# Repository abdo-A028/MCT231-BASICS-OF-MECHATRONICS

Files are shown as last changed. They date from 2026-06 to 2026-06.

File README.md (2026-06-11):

# MCT231-BASICS-OF-MECHATRONICS
MCT231 Mechatronics Project: A fully integrated, standalone system featuring sorting, lifting, and closed-loop projectile mechanisms. Built with a custom PCB, strict cable management, and robust safety standards. It includes Bluetooth PC comms, an on-board LCD, and a visual Processing GUI. Repo contains all Code, CAD, and Docs.
# PlanetSort: OrbitQuest 🌌

An autonomous, space-themed interactive mechatronic system designed as an educational STEM toy. The project features automated color-based planet sorting, continuous vertical elevator lifting, and a calibrated dual-wheel friction projectile launcher. 

Developed as the Final Project for the **Basics of Mechatronics (MCT231)** course under the partnership of **Ain Shams University** and the **University of East London**.

---

## 👥 Mission Control Team (Team #16)
* **Ziad Atef M. Riad** - ID: 24P0103
* **Kamal Wahdan** - ID: 24P0222
* **Zeyad Amr Nazih** - ID: 24P0372
* **Yahya Ashraf** - ID: 24P0370
* **Abdoulrahman Adel** - ID: 24P0098

---

## 📸 Physical Prototype Showcase

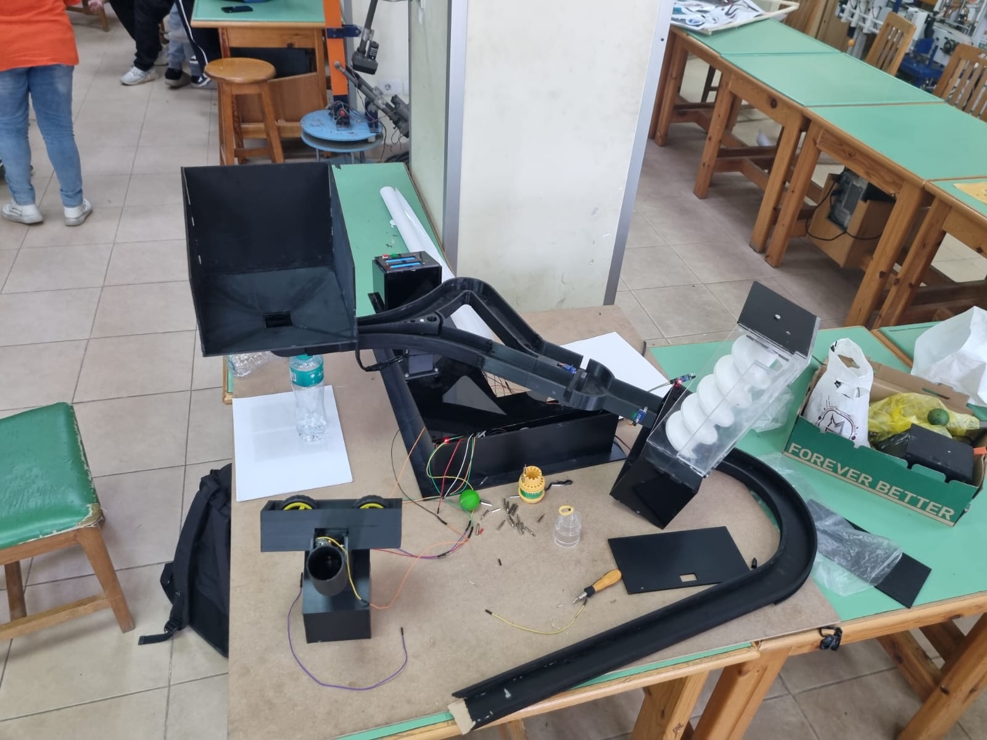
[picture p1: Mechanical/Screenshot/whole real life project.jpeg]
PlanetSort OrbitQuest System Setup


---

## 🚀 Project Architecture Overview
**PlanetSort: OrbitQuest** is engineered as a fully closed-loop, self-contained system running within a strict 100 cm x 100 cm x 100 cm volume. The product gamifies automation principles by treating different colored marbles as distinct planets navigating an interstellar transit grid. 

The system runs entirely off a single unified **12V DC power supply** and delegates tasks across a low-latency, wireless **Dual-ESP32 Master-Slave network** using the ESP-NOW protocol.

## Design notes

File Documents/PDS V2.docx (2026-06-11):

3. Product Design Specification (PDS)

The design and manufacturing boundaries of the PlanetSort: OrbitQuest mechatronic system are strictly governed by the following engineering criteria, established in accordance with course constraints and childhood safety standards:

Parameter ID | Category | Performance Requirement | Quantitative Target Metric | Priority (D/W) | Engineering Justification & Source
PDS-01 | Performance | Primary Functional Cycle | Complete autonomous color-based scanning, helical elevation, and parabolic projectile tracking. | D | Fulfills core mechatronic module requirements defined by the teaching committee.
PDS-02 | Performance | Closed-Loop Path Execution | 1 single ball loading point; 100 percent internal containment tracking throughout the complete operational loop. | D | Eradicates loose rolling pieces and ensures total containment of loose parts during the full loop.
PDS-03 | Mechanical | Ball Classification (Sorting) | Automated color identification via wavelength checks to separate balls into 2 divergent channels. | D | Driven by a TCS3200 sensor array acting on dual SG90 micro-servo flipper gates.
PDS-04 | Mechanical | Vertical Lifting Mechanism | Enclosed helical vertical transit lifting columns safely transporting marbles. | D | Employs an Archimedes spiral screw coupled to a NEMA 17 stepper motor running via an A4988 driver.
PDS-05 | Mechanical | Projectile Launch Subsystem | Friction-driven twin counter-rotating projection engine angled at a fixed incline. | D | Calibrated via PWM duty cycles to achieve an exit velocity of v0 = 4.15 m/s at a fixed 30-degree launch angle.
PDS-06 | Control | Embedded Processing Nodes | Dual-microcontroller processing grid mapping tasks across independent domains. | D | Deploys 2 x ESP32 DevKitC boards communicating wirelessly via low-latency peer-to-peer ESP-NOW protocol.
PDS-07 | Control | Local User Interface | Direct visual character menu terminal output (Seven-Segment configurations are strictly prohibited). | D | Employs 2 x onboard 16x4 character I2C LCD displays showing real-time subsystem state tracking.
PDS-08 | Control | Remote Monitoring Terminal | Wireless graphical monitoring software providing score and color parameter logging. | W | Achieved through a custom Processing.io application interacting via integrated Bluetooth Serial Port Profile.
PDS-09 | Electrical | Power Infrastructure | Single, unified power input terminal block layout supplying the entire backplane. | D | Eradicates independent secondary battery networks; safely driven by a single 12V, 5A DC adapter power source.
PDS-10 | Electrical | Onboard Voltage Regulation | Local voltage step-down buses to distribute isolated logic and actuator rails. | D | Integrates LM2596-based buck converter circuits on the custom PCB to step down 12V input to a stabilized 5V rail.
PDS-11 | Electrical | Custom Manufacturing | Clean signal routing and integration of system hardware components. | D | Mandates a minimum of 1 custom-manufactured PCB serving as the power distribution and circuit protection hub.
PDS-12 | Physical | Volumetric Footprint Bounds | Total external packaging bounds must remain within a compact structural envelope. | D | Maximum allowable boundaries of 100 cm x 100 cm x 100 cm; nominal layout optimized at 70 cm x 60 cm.
PDS-13 | Physical | Structural Composition | Non-toxic, rigid, drop-resistant material profiles with post-processed sanded facings. | D | Utilizes child-safe, deburred 3D-printed PLA mechanical paths mounted securely on a smooth 6 mm MDF baseboard.
PDS-14 | Physical | Structural Modularity | Subsystem mechanical arrays must cleanly decouple for maintenance. | D | Divided into 3 distinct modules (Sorting, Lifting, Shooting) using dedicated, polarized JST cable harnesses.
PDS-15 | Safety | Hazard & Shock Proofing | 100 percent concealment of electronic terminals and moving columns from user contact. | D | All electrical wiring is routed through integrated internal tracks; the helical lifter is encased inside clear acrylic.
PDS-16 | Safety | Ingestion Hazard Control | Planetary marble diameter sizing must remain strictly above choke testing cylinder limits. | D | Marble diameters are constrained between 35 mm and 40 mm to achieve compliance with global small parts toy safety criteria.
PDS-17 | Safety | Overcurrent Circuit Defense | Automatic hardware-level current trip points to protect logic lines if a mechanism stalls. | D | Features an inline, resettable polymeric 5A PTC fuse positioned immediately after the primary 12V DC power jack.
PDS-18 | Safety | Emergency System Shutdown | Instantaneous operational override path to halt all active actuators concurrently. | D | Physical, high-priority tactile push buttons configured to force immediate low-level hardware firmware interrupts.

The D/W Priority Filter: By explicitly labeling safety and course specifications as absolute a Demand (D) and a Wish (W), you show the panel that risk mitigation was treated as a primary engineering objective from day one.

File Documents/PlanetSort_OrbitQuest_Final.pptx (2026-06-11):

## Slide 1


PLANETSORT: ORBITQUEST

Advanced Interactive Mechatronic Product Design System

Ain Shams University · University of East London · Project Defense 2026

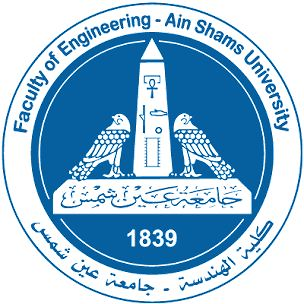
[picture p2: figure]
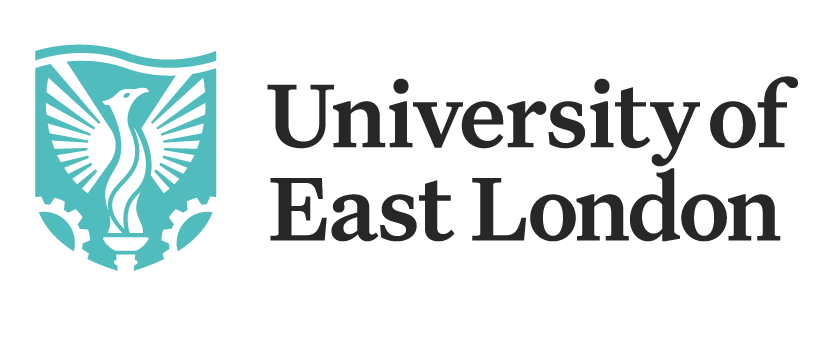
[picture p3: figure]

ARES SECTOR
RED ORBIT

GAEA SECTOR
GREEN ORBIT

Ziad Atef M. Riad
24P0103

Kamal Wahdan
24P0222

Zeyad Amr Nazih
24P0372

Yahya Ashraf
24P0370

Abdoulrahman Adel
24P0098

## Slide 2

PHASE I: VISION

Designing an autonomous, space-themed
planetary sorting and launching system

focused on cognitive development and STEM engagement.

Real project prototype — assembled for defense

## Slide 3

User Research & Target Persona

Primary Audience

Children aged 2–10 years. Focused research indicates high engagement for age 8 through visually stimulating mechanical feedback and goal-oriented tasks.

Core Needs

Visual stimulation (moving parts), color recognition, hand-eye coordination, and a safe, intuitive interface for 'closed-loop' play.

2–10

Target Age Range

3

Core Modules

100×100

cm Footprint

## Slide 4

The Design Challenge

Automated Sorting

Autonomous color detection and path routing using optical sensing logic.

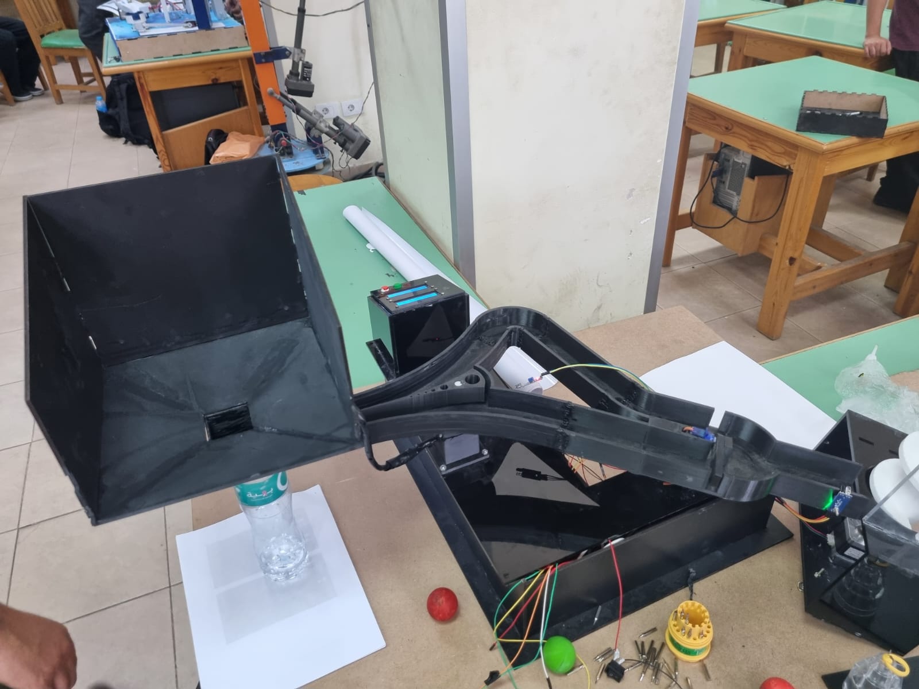
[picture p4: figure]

Vertical Lifting

Continuous vertical transit via an Archimedes spiral mechanism.

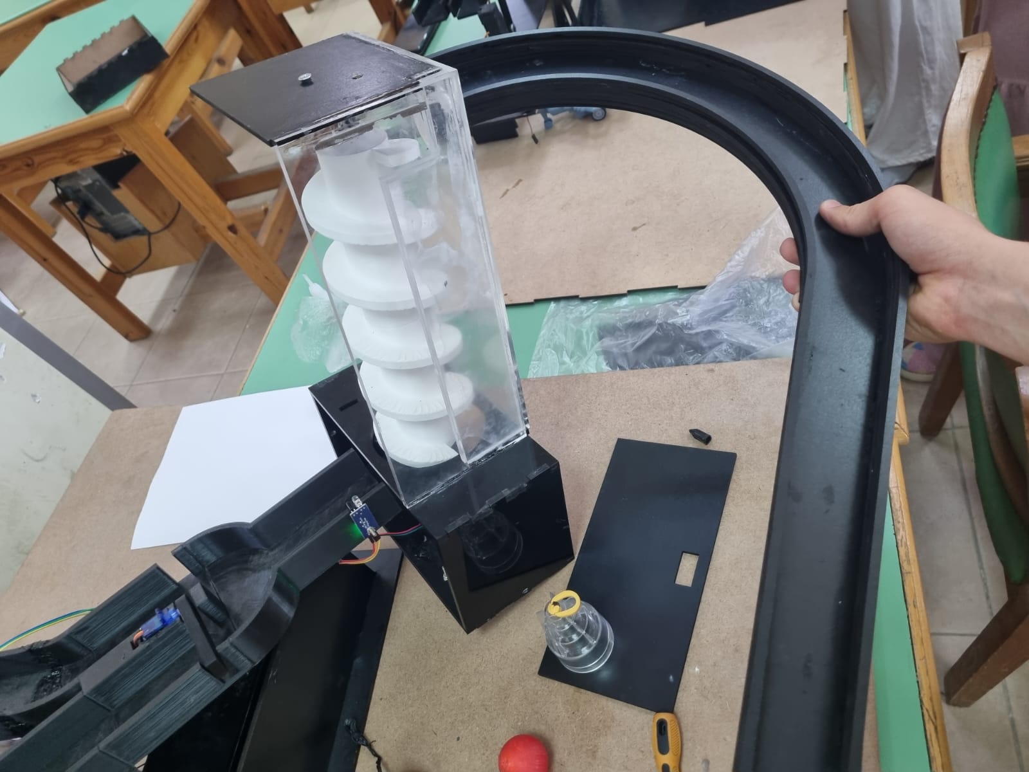
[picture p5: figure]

Orbital Launch

High-velocity calibrated projection into a target basketball hoop.

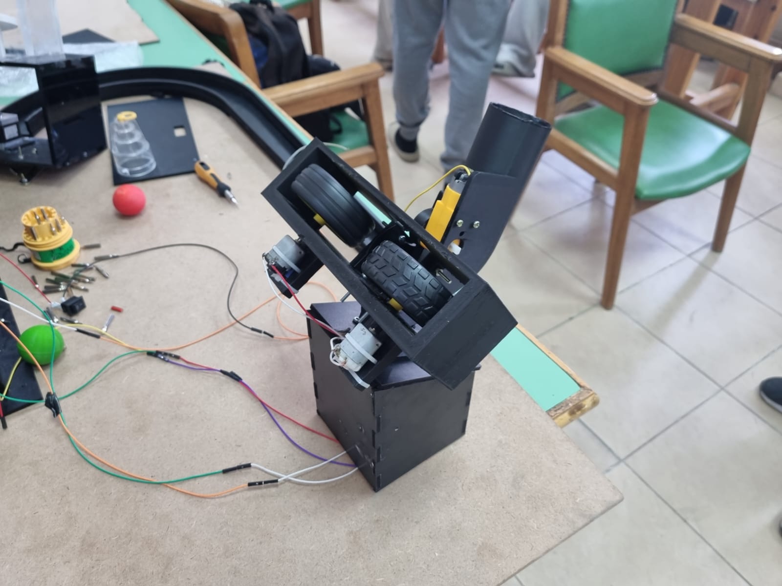
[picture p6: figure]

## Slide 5

Module I: PlanetScan Sorting

The sorting subsystem identifies planetary marbles by wavelength using the TCS3200 sensor array. Dual SG90 micro-servos actuate high-speed gates to route the spheres.

Real-time RGB frequency analysis

Non-contact optical gating

Dynamic error-correction routing

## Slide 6

Module II: Orbital Elevator

Our lifting mechanism utilizes a NEMA 17 stepper motor to drive a 3D-printed helical flight screw within a smooth-walled cylinder.

This module provides precise vertical positioning for the launch bay, ensuring the system is ready for the high-velocity shooting phase.

NEMA 17 Stepper

Motor:

Archimedes Spiral

Mechanism:

3D-Printed PLA

Material:

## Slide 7

Module III: Hyperspace Thruster

The shooting module utilizes twin counter-rotating friction wheels driven by high-RPM DC motors. Calibration ensures repeatable orbital injection.

By modulating the PWM duty cycle, we achieve the precise initial velocity required to overcome gravity and reach the target hoop.

4.15 m/s

Calibrated Launch Velocity · β = 30°

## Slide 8

Master-Slave Control Logic

ESP32 Master

Handles high-level tasks: Color sensing, TFT display, Bluetooth telemetry, and ESP-NOW communication with the slave controller.

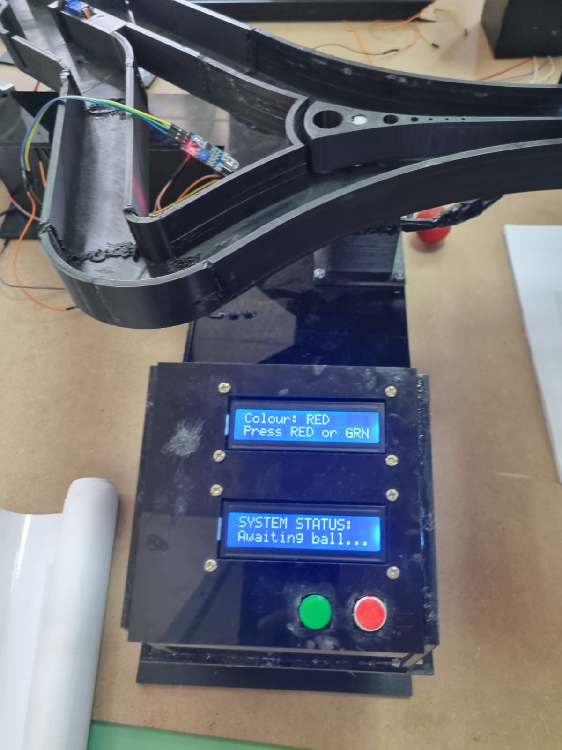
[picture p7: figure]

Arduino Uno Slave

Dedicated to low-level actuation: Precise stepper pulses, DC motor PWM curves, and servo timing isolation.

Communication via ESP-NOW wireless protocol · 2.4 GHz band

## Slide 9

Dual Interfaces: Mission Control

LCD Control Panel

Local onboard display · Colour detection readout
Green & Red button input

Ball Sorter App

Bluetooth remote control · Score tracking
Shoot speed slider · RGB sensor raw data

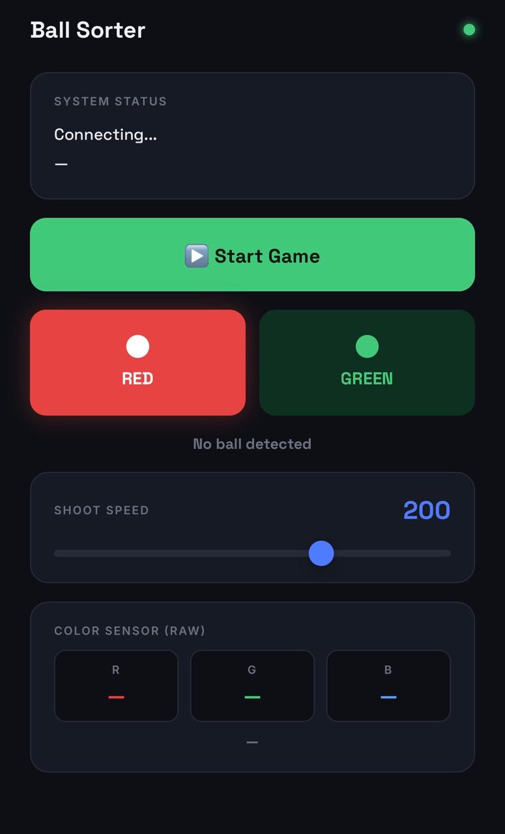
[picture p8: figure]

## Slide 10

Engineering Validation

v_o = d/(cos(β)) × √(g/(2(d·tan(β)− h)))≈ 4.15 m/s

Parameter | Value | Validation Status
Initial Velocity (v₀) | 4.15 m/s | Calculated & Tested
Launch Angle (β) | 30° | Fixed Mechanical Constraint
Current Draw (Max) | < 5.0 A | Fused Safety Limit
Motor Safety Factor | > 2.2 | Industry Standard Compliant

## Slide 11

Safety & Compliance Protocols

Concealed Architecture

All electrical wiring routed through internal structural channels to remain completely hidden and safe.

Thermal Safety

Onboard resettable 5A PTC fuse safeguards logic and motor rails against stall-current overloads and overheating.

Child-Safe Materials

Non-toxic PLA and smoothed MDF surfaces eliminate sharp edges and chemical exposure risks.

Hardware Interrupt

A physical master-stop button provides immediate electrical isolation of all high-power actuators.

OrbitQuest: Launching Curiosity into STEM · Ain Shams University & University of East London · Project Defense 2026

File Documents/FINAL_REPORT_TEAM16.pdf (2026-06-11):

## 16Table of Contents

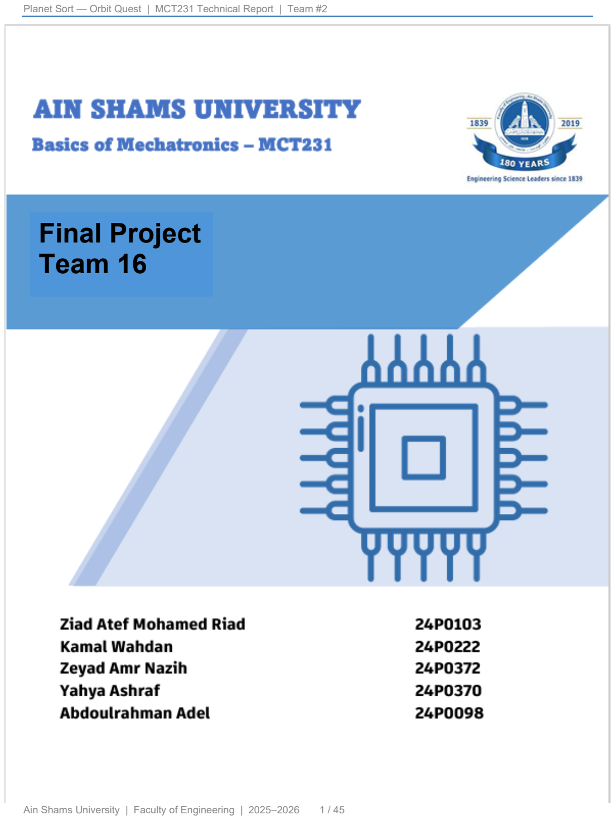
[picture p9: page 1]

Planet Sort — Orbit Quest | MCT231 Technical Report | Team #2
Ain Shams University | Faculty of Engineering | 2025–2026 1 / 45

# Final Project Team 16

Ain Shams University | Faculty of Engineering | 2025–2026 2 / 45

Ain Shams University | Faculty of Engineering | 2025–2026 3 / 45

Ain Shams University | Faculty of Engineering | 2025–2026 4 / 45

## 1. Introduction

Planet Sort (marketed to children as Orbit Quest) is an interactive, space-themed mechatronic toy designed for children aged 2–10. The toy presents a fully automated ball-sorting and launching system, where coloured planetary marbles are loaded, sorted by colour, lifted vertically via an Archimedes screw, and launched toward a target through a high-velocity shooting mechanism.
The project was developed as part of the MCT231 Basics of Mechatronics final project at Ain Shams University in collaboration with the University of East London. It integrates mechanical design, electronics, embedded firmware, and product design into a cohesive educational toy that fosters engagement, colour recognition, and curiosity in STEM topics.

### 1.1 Project Objectives

- Design and fabricate a fully functional electromechanical toy that integrates three distinct mechanisms: colour sorting, vertical lifting, and projectile shooting.
- Implement a dual-microcontroller architecture using two ESP32 boards communicating via the ESP-NOW wireless protocol.
- Provide two user interfaces: an onboard LCD display and a Bluetooth-connected Processing IO application.
- Ensure all mechanical, electrical, and firmware subsystems work as a closed-loop marble pathway.
- Document the complete design process from user research to final prototype.

Ain Shams University | Faculty of Engineering | 2025–2026 5 / 45

## 2. Design Thinking Process

### 2.1 User Research

The target audience was defined as children aged 2–10, with a primary engagement focus on children around 8 years old. User research revealed several key insights:
- Children in this age group are highly motivated by fast-moving, visually stimulating toys.
- Space and planetary themes score very high in engagement for both boys and girls.
- Simple, colour-based interactions are accessible even to younger children, while the automated mechanics provide complexity for older users.
- Safety is paramount: no sharp edges, no exposed wiring, and no small detachable parts that can be swallowed by younger children.

### 2.2 Design Challenge

The core design challenge was: How can we create a toy that is simultaneously engaging for a broad age range, educational in its interactions, safe by construction, and technically complex enough to demonstrate a complete mechatronic system?
The answer was to build a closed-loop automated machine themed around space and planet sorting, where the child's role is limited to choosing which colour marble to sort and watching the machine respond. This lowers the barrier of entry for younger children while still delighting older ones with the engineering of the system.

### 2.3 Ideation & Concept

Several concepts were explored via mind maps and mood boards before settling on the Planet Sort concept:
- Option A: Basketball-themed shooter with coloured balls. Relatable but not highly original.
- Option B: Recycling plant (similar to course example). Educational but less engaging visually.
- Option C: Planet Sort — space-themed sorting and launching of planetary marbles (Mars = red, Earth = green). Selected for its strong visual theme, broad age appeal, and alignment with all three required mechanisms.

### 2.4 Iterative Design

The design went through multiple iterations:
1. Initial sketches established the layout: screw lifter on the left, sorting gate in the middle channel, shooting mechanism at the top right.
2. CAD modelling in Autodesk Inventor refined dimensions and verified fit within the 100 cm × 100 cm constraint.
3. Wiring diagrams were drafted in Cirkit Designer, separating the three subsystems for modularity.
4. Physical prototyping with 3D-printed parts led to revisions in the screw pitch and the servo gate angle.

Ain Shams University | Faculty of Engineering | 2025–2026 6 / 45

## 3. Product Design Specification (PDS)

### 3.1 Performance & Functional Requirements

Requirement | Specification
Primary Function | Automated colour-based sorting, vertical lifting and projectile launching of planetary marbles.
Sorting Mechanism | TCS3200 colour sensor detects Red or Green marble. Two SG90 servo-driven gates direct the marble to the correct channel.
Lifting Mechanism | NEMA 17 stepper-driven Archimedes screw lifts marbles from the lower channel to the shooting platform.
Shooting Mechanism | Dual FA-130RA-18100 DC motors spinning rubber-rimmed wheels accelerate the marble to approx. 4.15 m/s at 30° launch angle over a 0.8 m range.
Closed-Loop Path | Single marble entry point; marbles remain within the internal track throughout operation.
User Interaction | Start/Stop button, Red/Green colour selection buttons, and onboard LCD display feedback.

### 3.2 Electronics & Control System

Parameter | Specification
Microcontrollers | 2× ESP32 (DevKitC). MCU1 handles sorting and lifting. MCU2 handles shooting and display.
Communication | ESP-NOW wireless peer-to-peer protocol (low-latency, no router required).
User Interface 1 | 2× 16×4 I2C LCD displays showing system state, selected colour, and mode (manual / Bluetooth).
User Interface 2 | Processing IO Bluetooth application on Android/PC — Start, Stop, colour selection.
Custom PCB | Power distribution board with 12 V input, PTC fuse, reverse-polarity diode, 12 V→5 V buck converter, and modular connectors for all subsystems.
Power Source | Single 12 V DC supply (adapter or 12 V LiPo battery). Four buck converters regulate to 5 V for logic and servos.

### 3.3 Physical & Material Specifications

Parameter | Specification
Dimensions | Maximum 100 cm × 100 cm footprint. Nominal design: ~70 cm × 60 cm.
Materials | PLA 3D-printed structural and mechanical parts. MDF base board. Smooth surfaces with no sharp edges.
Modularity | Three independent wiring modules (Sorting, Lifting, Shooting) with dedicated JST plug connectors to a central PCB.

Ain Shams University | Faculty of Engineering | 2025–2026 | 7 / 45
Safety | All wiring concealed inside channels. No exposed moving pinch points. Marble diameter >35 mm (not a choking hazard for ages 2+).

### 3.4 Target Audience

- Primary: Children aged 6–10 years — full autonomous use.
- Secondary: Children aged 2–5 years — supervised play; adult loads marbles and selects colour.
- Tertiary: Parents/educators — observe educational value in STEM, colour recognition, and cause-and-effect reasoning.

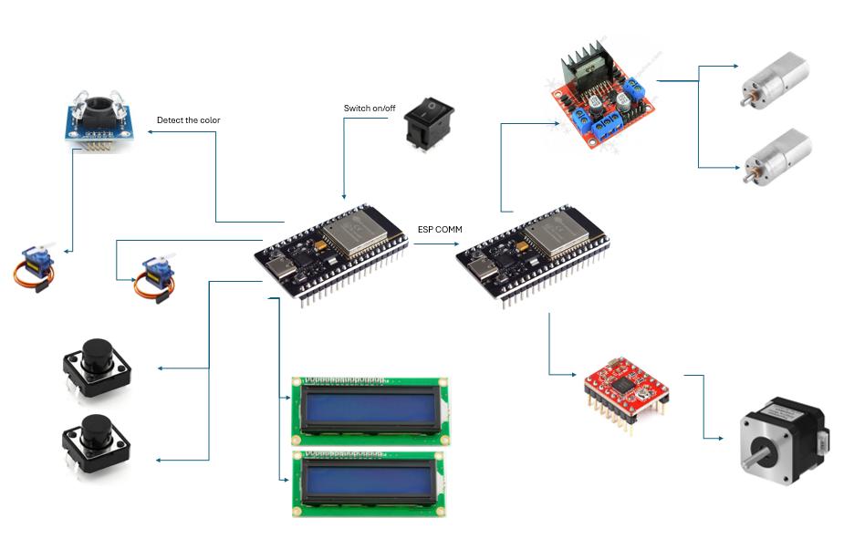
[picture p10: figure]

Ain Shams University | Faculty of Engineering | 2025–2026 8 / 45

## 4. System Architecture

### 4.1 Block Diagram Overview

The system is divided into two microcontroller domains connected by ESP-NOW wireless communication:

MCU 1 — Sorting & User Input (ESP32 #1)
- Inputs: TCS3200 colour sensor, Colour 1 button, Colour 2 button, On/Off switch.
- Outputs: Selecting servo (path gate), Sorting servo (end gate), 16×4 I2C LCD display #1.
- Transmits: Colour decision and start/stop command to MCU2 via ESP-NOW.

MCU 2 — Lifting, Shooting & Feedback (ESP32 #2)
- Inputs: ESP-NOW message from MCU1.
- Outputs: A4988 stepper driver → NEMA 17 (Archimedes screw), L298N H-bridge → 2× DC motors (shooting wheels), 16×4 I2C LCD display #2.

### 4.2 System Flowchart

The following describes the operational logic of the complete system:
5. Balls are placed into the selection mechanism (entry point). System starts on button press.
6. Default colour is set to Colour 1 (Green). LCD outputs 'Select Color'.
7. User presses Green or Red button (or selects via Bluetooth app).
8. Is Color 1 (Green) selected? If YES: Path 1 stays open. If NO: Path 1 closes, Path 2 opens.
9. Ball moves through the selected path to the sorting mechanism.

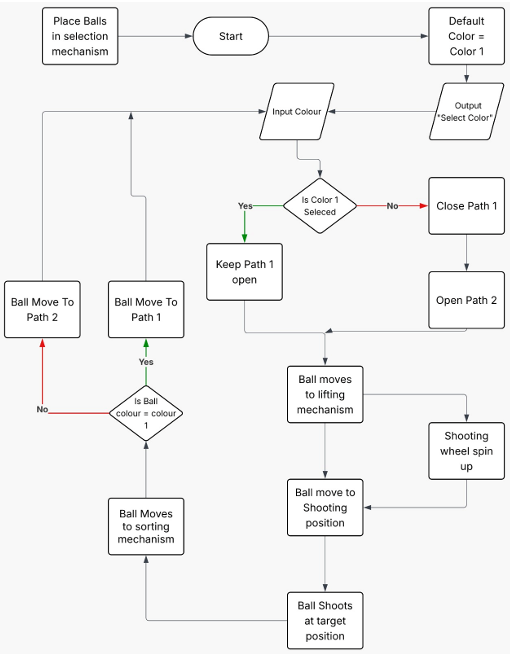
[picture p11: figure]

Ain Shams University | Faculty of Engineering | 2025–2026 9 / 45
10. Colour sensor reads the ball. Is ball colour = selected colour? If YES: Ball moves to lifting mechanism. If NO: Ball returns to sorting mechanism.
11. Ball is lifted by Archimedes screw to shooting platform.
12. Shooting wheels spin up to operating speed (~1,743 rpm).
13. Ball moves to shooting position and is launched toward target.
14. Cycle completes; system awaits next ball or Stop command.

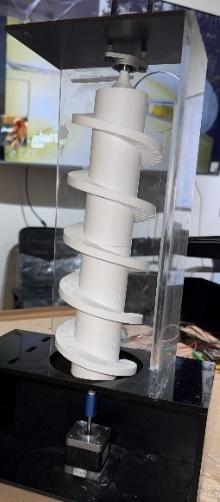
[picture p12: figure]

Ain Shams University | Faculty of Engineering | 2025–2026 10 / 45

## 5. Mechanical Design

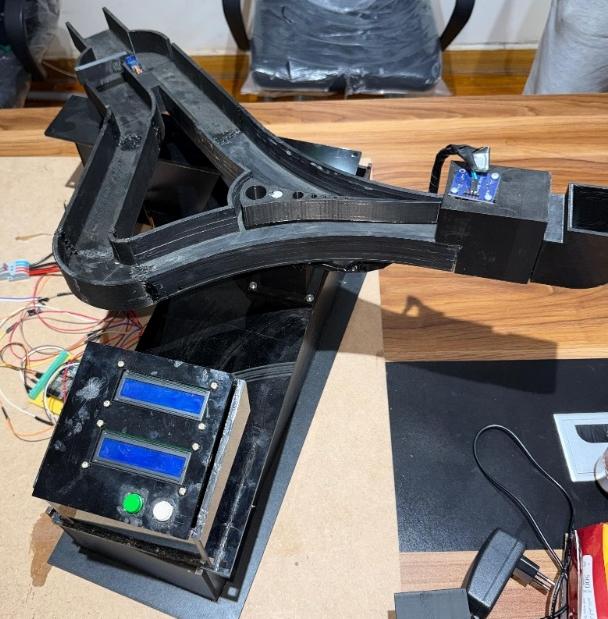
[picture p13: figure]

### 5.1 Sorting Mechanism

The sorting mechanism uses two SG90 micro servo motors to actuate gate flaps within the marble channel:
- Selecting Servo: Acts as the initial path router. When Color 1 is selected, the flap remains in position to keep Path 1 open. When Color 2 is selected, the flap rotates to close Path 1 and open Path 2.
- Sorting Servo (End Gate): Positioned at the output of the colour-sensing zone. After the TCS3200 confirms the correct colour, this servo opens to release the marble to the lifting mechanism. If the colour does not match, it redirects the marble back.
- CAD: Both gate mechanisms are 3D-printed in PLA. Servo horn connectors are press-fit with M2 screws for easy replacement.

### 5.2 Lifting Mechanism — Archimedes Screw

The vertical lifting mechanism is based on an Archimedes screw — a helical blade wound around a central shaft enclosed in a smooth cylindrical tube:
- Motor: NEMA 17 stepper motor (operating at ~500 rpm) drives the screw shaft via a direct-drive coupler.
- Screw dimensions: Pitch and diameter sized to accept marbles of 35–40 mm diameter and transport one marble per revolution reliably.
- The enclosed tube prevents marbles from falling sideways and contributes to the closed-loop pathway requirement.
- All parts 3D-printed in PLA. The screw was printed in sections and assembled on the shaft.

### 5.3 Shooting Mechanism

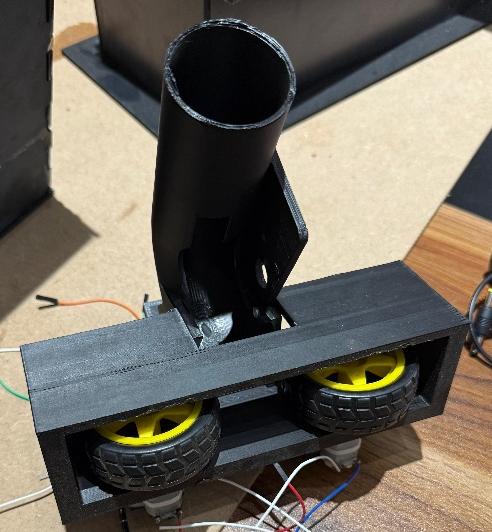
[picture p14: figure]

The shooting mechanism uses a dual-wheel friction launcher, widely used in table tennis ball machines and youth sports equipment:
- Two FA-130RA-18100 DC motors each drive a rubber-rimmed PLA wheel (~65 mm diameter, 35 g).
- The wheels are arranged facing each other with a gap slightly smaller than the marble diameter, creating a compression grip.
- When the marble is fed between the spinning wheels, friction accelerates it to the calculated exit velocity (~4.15 m/s).
- Motor driver: L298N H-bridge controlled via PWM from MCU2, allowing speed adjustment.
- Launch angle: 30° above horizontal, achieving a 0.8 m horizontal range at a 0.2 m height difference to the target hoop.

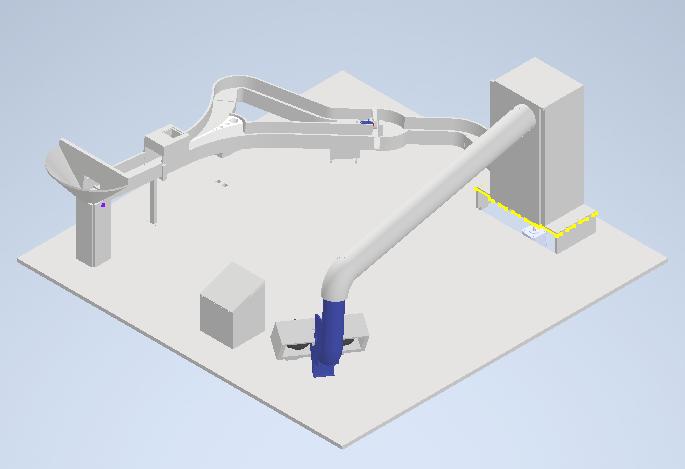
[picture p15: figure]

Ain Shams University | Faculty of Engineering | 2025–2026 11 / 45

### 5.4 Fully Integrated CAD Assembly

The complete assembly was modelled in Autodesk Inventor. Key design decisions:
- Base plate: 700 mm × 600 mm MDF, within the 100 cm × 100 cm constraint.
- The Archimedes screw tower is positioned at the rear-left corner with height ~350 mm.
- The ball channel runs along the base from the entry point (front-right) through the sorting zone to the screw base (rear-left) and back to the shooter (top of screw, directed right).
- The target hoop is mounted at the rear-right, aligned with the 30° shooting trajectory.
- Wire routing channels are integrated into all structural parts to keep wiring completely hidden.

Ain Shams University | Faculty of Engineering | 2025–2026 12 / 45

## 6. Electrical Design

### 6.1 Component Summary

# | Component | Role | Interface | Qty

1 | ESP32 DevKitC | Main microcontrollers | GPIO, I2C, PWM | 2
2 | TCS3200 Colour Sensor | Ball colour detection | Digital GPIO | 1
3 | SG90 Micro Servo | Sorting & selecting gates | PWM | 2
4 | NEMA 17 Stepper Motor | Archimedes screw drive | A4988 driver | 1
5 | A4988 Stepper Driver | NEMA 17 control | STEP/DIR PWM | 1
6 | FA-130RA-18100 DC Motor | Shooting wheels | L298N H-Bridge | 2
7 | L298N H-Bridge Module | DC motor drive | PWM GPIO | 1
8 | 16×4 I2C LCD Display | User feedback | I2C (SDA/SCL) | 2
9 | 12 V→5 V Buck Converter | Logic/servo power | Power rail | 4
10 | Custom PCB (Power Dist.) | Power routing, protection | Terminal blocks | 1
11 | Push Buttons (12 mm) | Colour select, Start/Stop | Digital GPIO | 4
12 | Rocker Switch | Main power On/Off | Power rail | 1
13 | 12 V DC Power Supply / LiPo | Single power source | – | 1

### 6.2 Wiring Diagram Overview

The electrical system is divided into three independent wiring modules. Each module has its own cable harness terminated with JST connectors, which plug into the central custom PCB for easy assembly and maintenance.

### 6.2.1 Sorting Module (MCU1)

- Arduino 1 (ESP32) ↔ TCS3200: S0, S1, S2, S3 (GPIO outputs), OUT (GPIO input), LED enable, VCC/GND.
- Arduino 1 ↔ Selecting Servo: PWM signal + 5 V / GND.
- Arduino 1 ↔ Sorting Servo: PWM signal + 5 V / GND.
- Arduino 1 ↔ LCD Display #1: SDA/SCL (I2C), 5 V / GND.
- Colour 1 & Colour 2 push-buttons: pulled up internally, connected to GPIO with GND.
- 5 V supply via terminal block from PCB buck converter.

### 6.2.2 Lifting Module (MCU1 → A4988 → NEMA 17)

- Arduino 1 ↔ A4988: STEP (PWM), DIR (GPIO), ENA (GPIO), MS1/MS2/MS3 (microstepping select), SLEEP/RESET.
- A4988 VMOT: 12 V from PCB. VDD: 5 V from buck. B1/B2/A1/A2: NEMA 17 coil pairs.
- 100 µF decoupling capacitor across VMOT/GND of A4988.

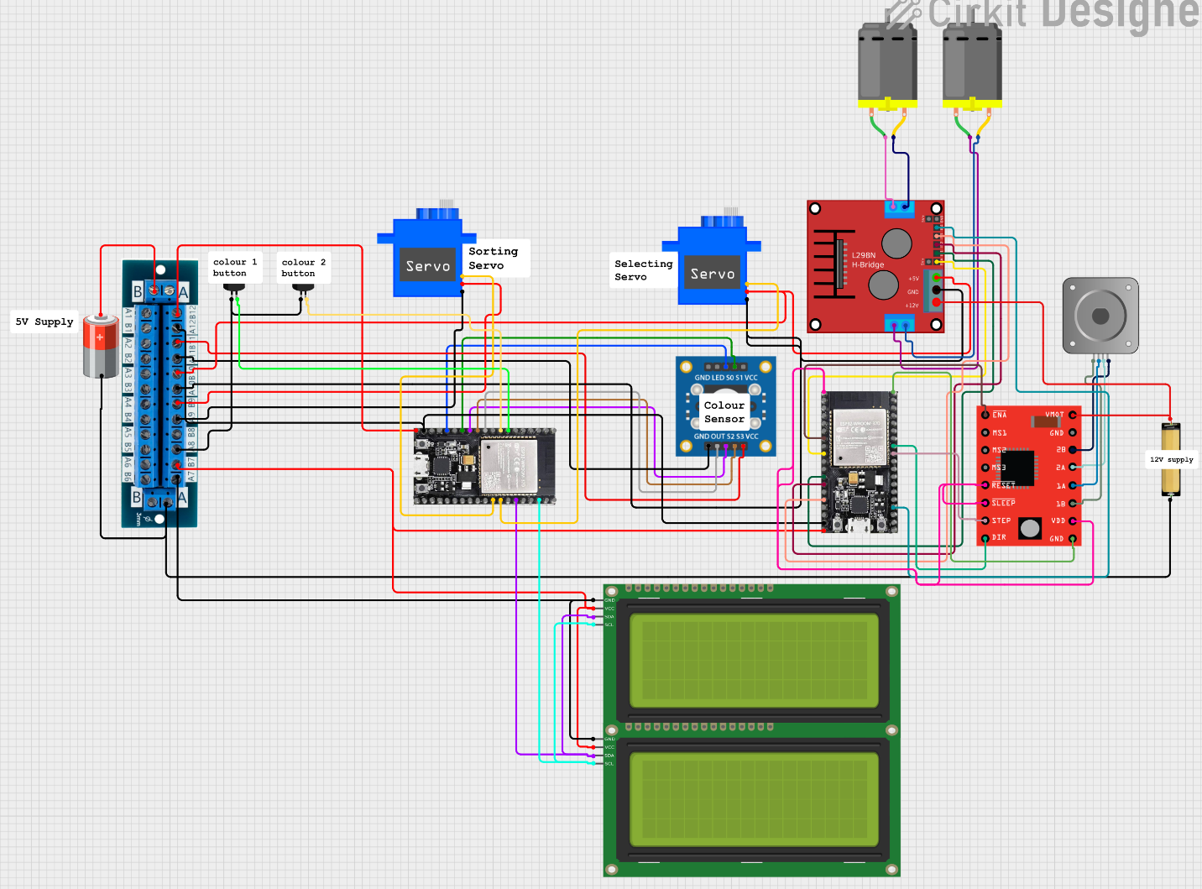
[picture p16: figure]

Ain Shams University | Faculty of Engineering | 2025–2026 13 / 45

### 6.2.3 Shooting Module (MCU2)

- Arduino 2 (ESP32) ↔ L298N: ENA (PWM), IN1/IN2 (direction), ENB (PWM), IN3/IN4 (direction).
- L298N OUT1/OUT2 → DC Motor Left (shooting wheel). OUT3/OUT4 → DC Motor Right.
- L298N +12 V from PCB, +5 V from on-board regulator. GND common.
- Arduino 2 ↔ LCD Display #2: SDA/SCL (I2C), 5 V / GND.

https://app.cirkitdesigner.com/project/e711d32f-553b-48ab-a936-7aebbb711319

### 6.3 Custom PCB

The custom PCB serves as the power distribution and protection hub for the entire toy. Key features:
- Input: 2-pin JST connector (J2) accepting 12 V DC.
- Reverse-polarity protection: 1N5822 Schottky diode (D1).
- Over-current protection: PTC resettable fuse (F1) rated at 5 A.
- 12 V→5 V Buck converter (LM2596-based) with 100 µF input and 1000 µF output capacitors, 10 µH inductor.
- Output connectors: Servo mover 1, Servo end gate, Right motor, Left motor, Stepper 1, Arduino R4 (5 V regulated).
- Ground plane poured across the full board for noise immunity.

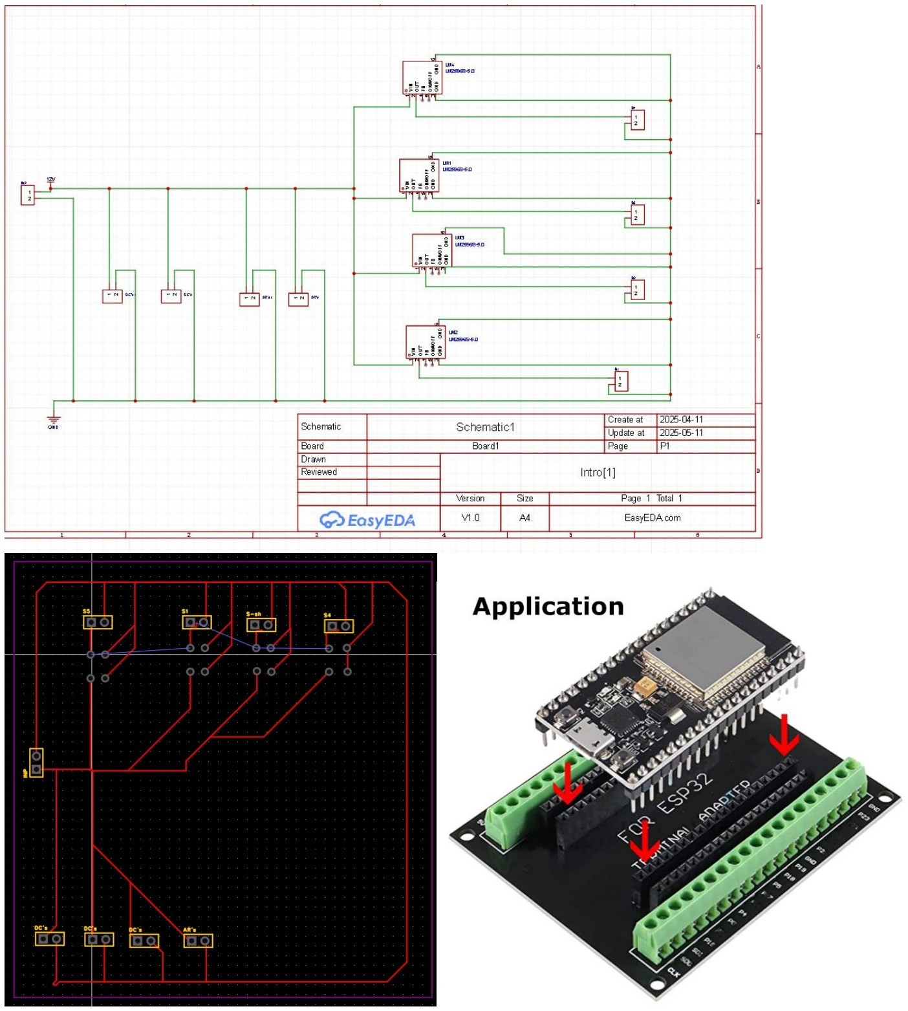
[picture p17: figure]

Ain Shams University | Faculty of Engineering | 2025–2026 14 / 45

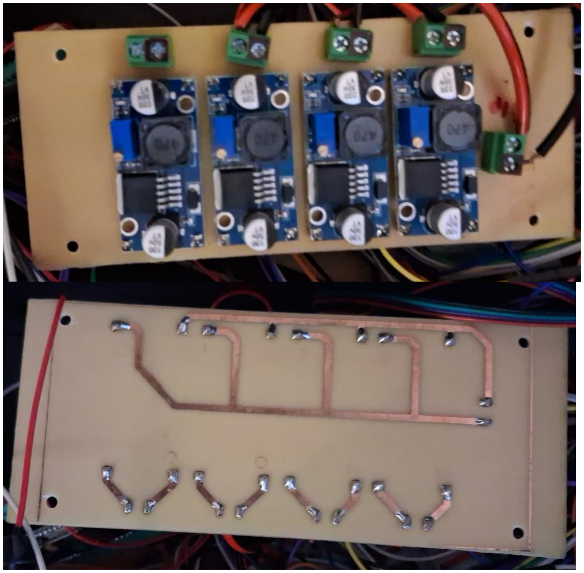
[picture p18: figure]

Ain Shams University | Faculty of Engineering | 2025–2026 15 / 45

## 7. Firmware & Control

### 7.1 MCU1 — Sorting & Lifting (ESP32 #1)

MCU1 is responsible for all input handling and the sorting and lifting subsystems. The firmware structure is:
- Initialisation: Set up I2C LCD, configure TCS3200 frequency pins, attach servo objects, configure button GPIO with internal pull-ups.
- Main Loop: Poll colour selection buttons. If pressed, update selectedColour variable and display on LCD.
- On Start command: Actuate Selecting Servo to open correct path. Read TCS3200 output. If colour matches selectedColour, release Sorting Servo gate, then send ESP-NOW trigger message to MCU2 to run the lifting sequence.

Ain Shams University | Faculty of Engineering | 2025–2026 16 / 45
- ESP-NOW Transmit: MCU1 broadcasts a struct containing {command: LIFT_AND_SHOOT, colour: selected} to MCU2 MAC address.
- LCD Display: Shows 'SYSTEM: READY', 'COLOR: GREEN', 'MODE: MANUAL' etc. based on state machine.
Here is the code:
/*
* ============================================================ * ESP1 — SLAVE SUBSYSTEM (Lifter & Shooter)
* MAC: 5C:01:3B:34:3A:64
*
* Responsibilities:
* - Wait for IR_BOTTOM → lift ball with stepper motor * - Wait for IR_TOP → fire shooting motors
* - Receive selectedColour from ESP2 via ESP-NOW * - Broadcast real-time status strings back to ESP2 * so ESP2 can display them on LCD2 (0x27)
*
* ESP-NOW Peer: ESP2 → 3C:8A:1F:AF:CF:98
* ============================================================ */

#include <esp_now.h>

#include <WiFi.h>

// ── STEPPER (A4988 / DRV8825) ──────────────────────────────── #define STEP_PIN 18
#define DIR_PIN 19

#define ENABLE_PIN 32 // LOW = enabled, HIGH = disabled

// ── IR SENSORS (LOW = ball detected) ──────────────────────── #define IR_BOTTOM 27
#define IR_TOP 33

// ── SHOOTING MOTORS (L298N) ────────────────────────────────── #define IN1 14
#define IN2 12

#define IN3 13

#define IN4 15

#define ENA 25

#define ENB 26

// ── SHOOTING SPEED (0–255) ──────────────────────────────────── int shootSpeed = 200;

// ── STATE ──────────────────────────────────────────────────── bool lifting = false;
bool shooting = false;

Ain Shams University | Faculty of Engineering | 2025–2026 17 / 45 unsigned long shootStartTime = 0;
const unsigned long SHOOT_DURATION_MS = 1000; // motors run 1 s

// ── ESP-NOW ────────────────────────────────────────────────── uint8_t esp2MAC[] = {0x3C, 0x8A, 0x1F, 0xAF, 0xCF, 0x98};

// Incoming: colour chosen on ESP2
typedef struct IncomingColour {
uint8_t selectedColour; // 1=RED 2=GREEN 0=none } IncomingColour;

// Outgoing: status lines for ESP2's LCD2
typedef struct StatusMsg {
char line1[17];
char line2[17];
} StatusMsg;

IncomingColour receivedData;
volatile bool newColourReceived = false;
uint8_t currentColour = 0;

// ── HELPERS ────────────────────────────────────────────────── void sendStatus(const char *l1, const char *l2) {
StatusMsg msg;
strncpy(msg.line1, l1, 16); msg.line1[16] = '\0';
strncpy(msg.line2, l2, 16); msg.line2[16] = '\0'; esp_now_send(esp2MAC, (uint8_t *)&msg, sizeof(msg));
Serial.printf("[TX Status] '%s' | '%s'\n", msg.line1, msg.line2);
}

void stopShooter() {
analogWrite(ENA, 0);
analogWrite(ENB, 0);
digitalWrite(IN1, LOW); digitalWrite(IN2, LOW); digitalWrite(IN3, LOW); digitalWrite(IN4, LOW); }

void startShooter() {
digitalWrite(IN1, HIGH); digitalWrite(IN2, LOW); digitalWrite(IN3, HIGH); digitalWrite(IN4, LOW); analogWrite(ENA, shootSpeed); analogWrite(ENB, shootSpeed);
}

void enableStepper() { digitalWrite(ENABLE_PIN, LOW); }

Ain Shams University | Faculty of Engineering | 2025–2026 18 / 45 void disableStepper() { digitalWrite(ENABLE_PIN, HIGH); }

void stepOnce() {
digitalWrite(STEP_PIN, HIGH); delayMicroseconds(1500); digitalWrite(STEP_PIN, LOW); delayMicroseconds(1500);
}

// ── ESP-NOW CALLBACKS ──────────────────────────────────────── void onDataSent(const wifi_tx_info_t *info, esp_now_send_status_t status) {
// silent — status TX confirmations not needed
}

void onDataReceived(const esp_now_recv_info_t *info, const uint8_t *data, int len) { if (len == sizeof(IncomingColour)) {
memcpy(&receivedData, data, sizeof(IncomingColour));
newColourReceived = true;
}
}

// ============================================================ void setup() {
Serial.begin(115200);
delay(500);

// ── STEPPER ────────────────────────────────────────────── pinMode(STEP_PIN, OUTPUT);
pinMode(DIR_PIN, OUTPUT);
pinMode(ENABLE_PIN, OUTPUT);
digitalWrite(DIR_PIN, LOW);
disableStepper(); // off at boot

// ── IR SENSORS ─────────────────────────────────────────── pinMode(IR_BOTTOM, INPUT);
pinMode(IR_TOP, INPUT);

// ── SHOOTER MOTORS ─────────────────────────────────────── pinMode(IN1, OUTPUT); pinMode(IN2, OUTPUT);
pinMode(IN3, OUTPUT); pinMode(IN4, OUTPUT);
pinMode(ENA, OUTPUT); pinMode(ENB, OUTPUT);
stopShooter();

// ── ESP-NOW ────────────────────────────────────────────── WiFi.mode(WIFI_STA);
Serial.print("ESP1 MAC: "); Serial.println(WiFi.macAddress());

if (esp_now_init() != ESP_OK) {

Ain Shams University | Faculty of Engineering | 2025–2026 19 / 45

Serial.println("[ERROR] ESP-NOW init failed"); return;
}
esp_now_register_send_cb(onDataSent); esp_now_register_recv_cb(onDataReceived);

esp_now_peer_info_t peer = {}; memcpy(peer.peer_addr, esp2MAC, 6); peer.channel = 0;
peer.encrypt = false;
if (esp_now_add_peer(&peer) != ESP_OK) { Serial.println("[ERROR] Failed to add ESP2 peer"); }

sendStatus("ESP1 ONLINE ", "Awaiting ball..."); Serial.println("--- ESP1 Slave Ready ---");
}

// ============================================================ void loop() {
unsigned long now = millis();

// ── HANDLE NEW COLOUR FROM ESP2 ────────────────────────── if (newColourReceived) {
newColourReceived = false;
currentColour = receivedData.selectedColour;
const char *colName = (currentColour == 1) ? "RED" : (currentColour == 2) ? "GREEN" : "NONE"; Serial.printf("[RX] Colour received: %s\n", colName);

char l2[17];
snprintf(l2, sizeof(l2), "Target: %-6s ", colName); sendStatus("SYSTEM STATUS: ", l2);
}

// ════════════════════════════════════════════════════════ // LIFTING — triggered by IR_BOTTOM
// ════════════════════════════════════════════════════════ int bottomSensor = digitalRead(IR_BOTTOM);
int topSensor = digitalRead(IR_TOP);

if (bottomSensor == LOW && !lifting && !shooting) { lifting = true;
enableStepper();
Serial.println("[IR_BOTTOM] Ball detected → lifting"); sendStatus("SYSTEM STATUS: ", "Lifting ball... "); }

Ain Shams University | Faculty of Engineering | 2025–2026 20 / 45

if (lifting) {
stepOnce(); // non-blocking single step each loop pass
}

// ════════════════════════════════════════════════════════ // TOP REACHED — stop lift, fire shooter
// ════════════════════════════════════════════════════════ if (topSensor == LOW && lifting) {
lifting = false;
disableStepper();
Serial.println("[IR_TOP] Ball at top → shooting");

shooting = true;
shootStartTime = now;
startShooter();

// Report which colour is being shot
const char *colName = (currentColour == 1) ? "RED" : (currentColour == 2) ? "GREEN" : "BALL"; char l2[17];
snprintf(l2, sizeof(l2), "Shooting %-6s ", colName);
sendStatus("SYSTEM STATUS: ", l2);
}

// ════════════════════════════════════════════════════════ // SHOOT TIMEOUT — stop motors after SHOOT_DURATION_MS
// ════════════════════════════════════════════════════════ if (shooting && (now - shootStartTime >= SHOOT_DURATION_MS)) {
shooting = false;
stopShooter();
Serial.println("[SHOOT] Done → idle");
sendStatus("SYSTEM STATUS: ", "Awaiting ball..."); }
}

### 7.2 MCU2 — Shooting & Feedback (ESP32 #2)

MCU2 runs the stepper for lifting and the DC motors for shooting, coordinated by incoming ESP-NOW messages.
- On receive ESP-NOW LIFT_AND_SHOOT: Step NEMA 17 at 500 rpm for calculated number of steps to raise marble to shooting platform.
- Spin-up: Both DC motors ramped to full PWM (~1,743 rpm wheel speed) over 3 seconds via PWM increase.
- Feed: After spin-up, a brief servo or stepper pulse feeds the marble between the wheels.
- Shoot: Marble exits at calculated velocity; motors ramp down.
- LCD Display #2: Reflects received colour and mode in sync with MCU1.
Here is the code:

Ain Shams University | Faculty of Engineering | 2025–2026 21 / 45

/*
* ============================================================ * ESP2 — MASTER CONTROLLER (Color Sorter & Brain)
* MAC: 3C:8A:1F:AF:CF:98
*
* Responsibilities:
* - Read color sensor → sort balls via servo
* - Read RED/GREEN buttons → manage 20s lock timer
* - LCD1 (0x23) = User Interface (colour choice, countdown) * - LCD2 (0x27) = System Status (ESP1 operational feedback) * - Send selectedColour to ESP1 via ESP-NOW
* - Receive status string from ESP1 and display on LCD2
*
* ESP-NOW Peer: ESP1 → 5C:01:3B:34:3A:64
* ============================================================ */

#include <Wire.h>

#include <LiquidCrystal_I2C.h> #include <ESP32Servo.h>

#include <esp_now.h>

#include <WiFi.h>

// ── I2C ──────────────────────────────────────────────────── #define SDA_PIN 21
#define SCL_PIN 22

// ── COLOR SENSOR ──────────────────────────────────────────── #define S0 13
#define S1 12

#define S2 14

#define S3 27

#define sensorOut 26

// ── SERVOS ────────────────────────────────────────────────── #define SERVO_COLOR_PIN 19 // sorts balls
#define SERVO_BTN_PIN 18 // mirrors button selection

// ── BUTTONS (pressed = LOW via INPUT_PULLUP) ───────────────── #define BTN_RED 32
#define BTN_GREEN 33

// ── LCDs ──────────────────────────────────────────────────── LiquidCrystal_I2C lcdUI (0x23, 16, 2); // LCD1 — user interface
LiquidCrystal_I2C lcdStatus(0x27, 16, 2); // LCD2 — ESP1 status

Ain Shams University | Faculty of Engineering | 2025–2026 22 / 45

// ── SERVOS ────────────────────────────────────────────────── Servo myServo; // color sorting (pin 19)
Servo selectServo; // button mirror (pin 18)

// ── COLOR SENSOR READINGS ──────────────────────────────────── int freqR = 0, freqG = 0, freqB = 0;

// ── ESP-NOW ───────────────────────────────────────────────── uint8_t esp1MAC[] = {0x5C, 0x01, 0x3B, 0x34, 0x3A, 0x64};

// Outgoing: tells ESP1 which colour was selected
typedef struct OutgoingMsg {
uint8_t selectedColour; // 0=none 1=RED 2=GREEN } OutgoingMsg;

// Incoming: operational status from ESP1
typedef struct IncomingStatus {
char line1[17]; // up to 16 chars + null char line2[17];
} IncomingStatus;

OutgoingMsg toSend;
IncomingStatus esp1Status;
volatile bool newStatusFromESP1 = false;

// ── STATE MACHINE ──────────────────────────────────────────── enum SystemState { AWAITING_SELECTION, LOCKED, SELECTING, SORTING }; SystemState currentState = AWAITING_SELECTION;

int selectedColour = 0;

// ── TIMERS ────────────────────────────────────────────────── const unsigned long LOCK_DURATION_MS = 20000;
const unsigned long COLOR_CHECK_MS | = 1000;
const unsigned long UI_REFRESH_MS | = 500;
unsigned long lockStartTime | = 0;
unsigned long lastColorCheck | = 0;
unsigned long lastUIRefresh | = 0;
unsigned long sortingDisplayUntil = 0; // hold sorting msg on LCD2 for 3s
int | lastCountdownShown = -1;

// ── ESP-NOW CALLBACKS ──────────────────────────────────────── void onDataSent(const wifi_tx_info_t *info, esp_now_send_status_t status) { Serial.print("[ESP-NOW TX] ");
Serial.println(status == ESP_NOW_SEND_SUCCESS ? "OK" : "FAIL");

Ain Shams University | Faculty of Engineering | 2025–2026 23 / 45

}

void onDataReceived(const esp_now_recv_info_t *info, const uint8_t *data, int len) { if (len == sizeof(IncomingStatus)) {
memcpy(&esp1Status, data, sizeof(IncomingStatus));
newStatusFromESP1 = true;
}
}

// ── SEND COLOUR TO ESP1 ────────────────────────────────────── void sendColourToESP1() {
toSend.selectedColour = (uint8_t)selectedColour;
esp_now_send(esp1MAC, (uint8_t *)&toSend, sizeof(toSend));
Serial.printf("[TX] Sent colour %d to ESP1\n", selectedColour);
}

// ============================================================ void setup() {
Serial.begin(115200);
delay(500);

// ── I2C + LCDs ────────────────────────────────────────── Wire.begin(SDA_PIN, SCL_PIN, 100000);

lcdUI.init(); | lcdUI.backlight(); | lcdUI.clear();
lcdStatus.init(); lcdStatus.backlight(); lcdStatus.clear();

lcdUI.setCursor(0,0); lcdUI.print("Welcome User! "); lcdUI.setCursor(0,1); lcdUI.print("Select: R or G ");

lcdStatus.setCursor(0,0); lcdStatus.print("SYSTEM STATUS: "); lcdStatus.setCursor(0,1); lcdStatus.print("Waiting ESP1... ");

// ── COLOR SENSOR ──────────────────────────────────────── pinMode(S0, OUTPUT); pinMode(S1, OUTPUT);
pinMode(S2, OUTPUT); pinMode(S3, OUTPUT);
pinMode(sensorOut, INPUT);
digitalWrite(S0, LOW); digitalWrite(S1, HIGH); // 20% scaling

// ── BUTTONS ───────────────────────────────────────────── pinMode(BTN_RED, INPUT_PULLUP);
pinMode(BTN_GREEN, INPUT_PULLUP);

// ── SERVOS ────────────────────────────────────────────── ESP32PWM::allocateTimer(0);
ESP32PWM::allocateTimer(1);

Ain Shams University | Faculty of Engineering | 2025–2026 24 / 45 myServo.setPeriodHertz(50);
myServo.attach(SERVO_COLOR_PIN, 500, 2400); myServo.write(78);

selectServo.setPeriodHertz(50); selectServo.attach(SERVO_BTN_PIN, 500, 2400);
selectServo.write(90);

// ── ESP-NOW ───────────────────────────────────────────── WiFi.mode(WIFI_STA);
Serial.print("ESP2 MAC: "); Serial.println(WiFi.macAddress());

if (esp_now_init() != ESP_OK) {
Serial.println("[ERROR] ESP-NOW init failed"); lcdStatus.setCursor(0,1); lcdStatus.print("ESP-NOW FAILED! "); return;
}
esp_now_register_send_cb(onDataSent); esp_now_register_recv_cb(onDataReceived);

esp_now_peer_info_t peer = {}; memcpy(peer.peer_addr, esp1MAC, 6); peer.channel = 0;
peer.encrypt = false;
if (esp_now_add_peer(&peer) != ESP_OK) { Serial.println("[ERROR] Failed to add ESP1 peer"); }

Serial.println("--- ESP2 Master Ready ---");
}

// ============================================================ void loop() {
unsigned long now = millis();

// ── UPDATE LCD2 WITH ESP1 STATUS ──────────────────────── // Do not overwrite LCD2 while ESP2 itself is actively sorting a ball
if (newStatusFromESP1 && currentState != SORTING) {
newStatusFromESP1 = false;
lcdStatus.clear();
lcdStatus.setCursor(0,0); lcdStatus.print(esp1Status.line1); lcdStatus.setCursor(0,1); lcdStatus.print(esp1Status.line2);
}

// ════════════════════════════════════════════════════════ // STATE 1: AWAITING FIRST COLOUR SELECTION

Ain Shams University | Faculty of Engineering | 2025–2026 25 / 45

// ════════════════════════════════════════════════════════ if (currentState == AWAITING_SELECTION) {
if (digitalRead(BTN_RED) == LOW) {
selectedColour = 1;
selectServo.write(180);
currentState = LOCKED;
lockStartTime = now;
lastCountdownShown = -1;
sendColourToESP1();
delay(200);
}
else if (digitalRead(BTN_GREEN) == LOW) { selectedColour = 2;
selectServo.write(0);
currentState = LOCKED;
lockStartTime = now;
lastCountdownShown = -1;
sendColourToESP1();
delay(200);
}
}

// ════════════════════════════════════════════════════════ // STATE 2: LOCKED — countdown on LCD1, buttons ignored
// ════════════════════════════════════════════════════════ if (currentState == LOCKED) {
unsigned long elapsed = now - lockStartTime;

if (elapsed >= LOCK_DURATION_MS) { currentState = SELECTING;
lastCountdownShown = -1;
Serial.println("[LOCK] Expired — buttons unlocked."); lcdUI.clear();
lcdUI.setCursor(0,0); lcdUI.print("Change colour? "); lcdUI.setCursor(0,1); lcdUI.print("Press RED or GRN");
}
else {
int secsLeft = (int)((LOCK_DURATION_MS - elapsed + 999) / 1000); if (secsLeft != lastCountdownShown) {
lastCountdownShown = secsLeft;
lcdUI.clear();
lcdUI.setCursor(0,0);
lcdUI.print(selectedColour == 1 ? "Colour: RED " : "Colour: GREEN "); lcdUI.setCursor(0,1);
char buf[17];
snprintf(buf, sizeof(buf), "Locked [%2ds] ", secsLeft);

Ain Shams University | Faculty of Engineering | 2025–2026 26 / 45

lcdUI.print(buf);
}
}
}

// ════════════════════════════════════════════════════════ // STATE 3 / 4: SELECTING / SORTING — post-lock button input
// ════════════════════════════════════════════════════════ if (currentState == SELECTING || currentState == SORTING) {
if (digitalRead(BTN_RED) == LOW) {
selectedColour = 1;
selectServo.write(180);
sendColourToESP1();
lcdUI.clear();
lcdUI.setCursor(0,0); lcdUI.print("Colour: RED | ");
lcdUI.setCursor(0,1); lcdUI.print(" | ");
delay(200);
}
else if (digitalRead(BTN_GREEN) == LOW) { selectedColour = 2;
selectServo.write(0);
sendColourToESP1();
lcdUI.clear();
lcdUI.setCursor(0,0); lcdUI.print("Colour: GREEN ");
lcdUI.setCursor(0,1); lcdUI.print(" | ");
delay(200);
}
}

// ════════════════════════════════════════════════════════ // COLOR SENSOR — non-blocking, every 1 second
// ════════════════════════════════════════════════════════ if (now - lastColorCheck >= COLOR_CHECK_MS) {
lastColorCheck = now;

digitalWrite(S2, LOW); digitalWrite(S3, LOW); freqR = pulseIn(sensorOut, LOW); delay(10);

digitalWrite(S2, HIGH); digitalWrite(S3, HIGH); freqG = pulseIn(sensorOut, LOW); delay(10);

digitalWrite(S2, LOW); digitalWrite(S3, HIGH);
freqB = pulseIn(sensorOut, LOW); delay(10);

Serial.printf("Sensor R=%d G=%d B=%d\n", freqR, freqG, freqB);

Ain Shams University | Faculty of Engineering | 2025–2026 27 / 45 if (freqR < freqG && freqR < 35) {
myServo.write(68);
Serial.println("-> RED ball detected"); currentState = SORTING;
sortingDisplayUntil = millis() + 3000;
lcdStatus.clear();
lcdStatus.setCursor(0,0); lcdStatus.print("SORTING BALL... "); lcdStatus.setCursor(0,1); lcdStatus.print("Detected: RED "); }
else if (freqG < freqR && freqG < 30) {
myServo.write(88);
Serial.println("-> GREEN ball detected"); currentState = SORTING;
sortingDisplayUntil = millis() + 3000;
lcdStatus.clear();
lcdStatus.setCursor(0,0); lcdStatus.print("SORTING BALL... "); lcdStatus.setCursor(0,1); lcdStatus.print("Detected: GREEN "); }
else {
myServo.write(78);
if (currentState == SORTING && millis() >= sortingDisplayUntil) { currentState = SELECTING;
lcdStatus.clear();
lcdStatus.setCursor(0,0); lcdStatus.print("SYSTEM STATUS: "); lcdStatus.setCursor(0,1); lcdStatus.print("Selecting... ");
}
}
}

// ════════════════════════════════════════════════════════ // IDLE LCD1 REFRESH (rate-limited, no flicker)
// ════════════════════════════════════════════════════════ if (currentState != LOCKED && (now - lastUIRefresh >= UI_REFRESH_MS)) { lastUIRefresh = now;
if (currentState == AWAITING_SELECTION) {
lcdUI.setCursor(0,0); lcdUI.print("Welcome User! "); lcdUI.setCursor(0,1); lcdUI.print("Select: R or G "); }
else if (currentState == SELECTING) { lcdUI.setCursor(0,0);
if | (selectedColour == 1) lcdUI.print("Colour: RED | ");
else if (selectedColour == 2) lcdUI.print("Colour: GREEN ");
else | lcdUI.print("Change colour? ");
lcdUI.setCursor(0,1); lcdUI.print("Press RED or GRN");
}
}

Ain Shams University | Faculty of Engineering | 2025–2026 28 / 45

}

### 7.3 ESP-NOW Communication

ESP-NOW is a Espressif peer-to-peer wireless protocol that operates without a Wi-Fi router. Advantages for this application:
- Latency: Sub-millisecond typical message delivery — essential for real-time marble coordination.
- No network dependency: The toy works anywhere without internet or a router.
- Simple API: espnow_send() / espnow_recv_cb() used directly in Arduino framework.
- Packet structure: 8-byte struct {uint8_t cmd; uint8_t colour; uint8_t reserved[6]}.

### 7.4 User Interfaces

Interface 1 — LCD Displays
Two 16×4 character LCD displays with I2C backpacks (PCF8574 expander) are connected to MCU1 and MCU2 respectively. Display states:
- SYSTEM: READY — after power on, before start.
- COLOR: GREEN / RED — shows selected colour after button press.
- MODE: MANUAL / BT — indicates whether input came from physical button or Bluetooth.
- SORTING... / LIFTING... / SHOOTING... — real-time status during operation.

Interface 2 — Processing IO Bluetooth App
A Processing IO application running on a smartphone or PC communicates with MCU1 via Bluetooth (HC-05 module or ESP32 built-in Bluetooth Serial). The app provides:
- CONNECT button: Establishes Bluetooth serial link.
- START / STOP buttons: Send 'S' and 'X' characters to MCU1.
- GREEN / RED planet buttons: Send 'G' and 'R' characters to set colour selection remotely.
- Status panel: Receives and displays MCU1 serial responses ('READY', 'SORTING', 'DONE', etc.).

Ain Shams University | Faculty of Engineering | 2025–2026 29 / 45

## 8. Bill of Materials

# | Component | Specification / Model

Qty | Unit
(EGP)

Total
(EGP)

Subsystem

1 | ESP32 DevKitC | Espressif ESP32-WROOM-32 | 2 | 250 | 500 | Control
2 | NEMA 17 Stepper Motor | 1.7 A, 0.48 N·m | 1 | 350 | 350 | Lifting
3 | A4988 Stepper Driver | Pololu A4988 | 1 | 120 | 120 | Lifting
4 | FA-130RA-18100 DC Motor | 3–9 V, ~330 mA | 2 | 80 | 160 | Shooting
5 | L298N H-Bridge Module | 2 A per channel | 1 | 90 | 90 | Shooting
6 | SG90 Micro Servo | 1.3 kg·cm, 180° | 2 | 70 | 140 | Sorting
7 | TCS3200 Colour Sensor | Full spectrum, 8-pin DIP | 1 | 85 | 85 | Sorting
8 | 16×4 I2C LCD Display | PCF8574 backpack, 5 V | 2 | 110 | 220 | UI
9 | LM2596 Buck Converter | 12 V→5 V, 3 A | 4 | 60 | 240 | Power
10 | Custom PCB | Power distribution board | 1 | 200 | 200 | Power
11 | 12 mm Push Buttons | Momentary, 5 V | 4 | 15 | 60 | UI
12 | Rocker Switch | SPST, 10 A, 250 V | 1 | 20 | 20 | Power
13 | 12 V DC Power Adapter | 12 V, 5 A minimum | 1 | 180 | 180 | Power
14 | PLA Filament (1 kg) | White/Black, 1.75 mm | 1 | 250 | 250 | Mechanical
15 | MDF Board 70×60 cm | 6 mm thick | 1 | 80 | 80 | Mechanical
16 | JST Connectors (sets) | 2–4 pin, male/female | 10 | 15 | 150 | Wiring
17 | Wiring (mixed gauge) | AWG 22/24, colour coded | 1 set | 80 | 80 | Wiring
18 | M2/M3 Screw Sets | Stainless steel | 1 set | 30 | 30 | Mechanical
| | TOTAL | | | 2,955 EGP

Ain Shams University | Faculty of Engineering | 2025–2026 30 / 45

## 9. Engineering Calculations

### 9.1 Actuator Sizing — Sorting Mechanism

The sorting mechanism uses a servo to rotate an arm + gate assembly. The required torque is calculated from rotational inertia and angular acceleration.

Parameter | Value
J_shaft | 2.95 × 10⁻⁷ kg·m² (from Autodesk Inventor iProperties)
J_mover | 1.00 × 10⁻⁴ kg·m²
J_arm | 5.44 × 10⁻⁴ kg·m²
J_total (÷10 safety) | 1.11 × 10⁻⁴ kg·m²
Angular acceleration θ̈ | 523.2 rad/s² (60° rotation in 0.1 s → 600 °/s)
Required Torque T_m | T_m = J·θ̈+ T_R = 1.11×10⁻⁴ × 523.2 ≈ 0.0591 N·m = 0.591 kg·cm
Resistive Torque T_R | ≈ 0 (minimal friction, no external load)
Selected Motor | SG90 Micro Servo — T_stall = 1.3 kg·cm
Safety Factor n | n = 1.3 / 0.591 ≈ 2.20 ✓ (>2 acceptable)

### 9.2 Actuator Sizing — Lifting Mechanism

Parameter | Value
J_screw | 0.000551 kg·m²
J_coupler | 8.52 × 10⁻⁷ kg·m²
J_load total | 5.313 × 10⁻⁴ kg·m²
J_motor (NEMA 17) | 5.7 × 10⁻⁶ kg·m²
J_total | 5.567 × 10⁻⁴ kg·m²
ω operating | 31.41 rad/s (300 rpm nominal)
θ̈(spin-up) | 314.1 rad/s² (0 → 300 rpm in 0.1 s)
T_required | T_m > J_tot × θ̈= 5.567×10⁻⁴ × 314.1 > 0.175 N·m
Resistive Torque T_R | ≈ 0 (no external weight load on screw flight; balls float on helix)
Selected Motor | NEMA 17 Stepper — T_available = 0.48 N·m
Safety Factor n | n = 0.48 / 0.175 = 2.74 ✓
Operating Speed | ~500 ±50 rpm at constant torque

### 9.3 Actuator Sizing — Shooting Mechanism

Parameter | Value
Wheel radius r | 32.5 mm = 0.0325 m | Wheel mass m_w ≈ 35 g

Ain Shams University | Faculty of Engineering | 2025–2026 | 31 / 45
J_motor | 1.27 × 10⁻⁷ kg·m²
J_wheel (solid disc) | J_w = m·r² = 0.035 × (0.0325)² = 3.69 × 10⁻⁵ kg·m²
J_bearing | 7.2 × 10⁻⁷ kg·m²
J_total | ≈ 3.78 × 10⁻⁵ kg·m²
Spin-up time | 3 s → θ̈= 182.5/3 ≈ 60.8 rad/s²
Final ω | 182.5 rad/s → n = 1,743 rpm
T_required | T_m = J × θ̈= 3.78×10⁻⁵ × 60.8 ≈ 2.3 × 10⁻³ N·m
Selected Motor | FA-130RA-18100 with L298N H-bridge and PWM control

### 9.4 Projectile Calculations

The shooting mechanism must launch a marble from height h = 0.2 m below the target, over a horizontal distance d = 0.8 m, at launch angle β = 30°.

Parameter | Value
Launch angle β | 30°
Horizontal distance d | 0.8 m
Height difference h | 0.2 m (target above launcher)
Required V₀ | V₀ = (d / cos β) × √(g / 2(d·tan β − h)) = (0.8/cos30°) × √(9.81 / 2(0.8·tan30° − 0.2)) ≈ 4.15 m/s
Wheel efficiency η | η ≈ 0.7 (friction coupling)
Required v_tangential | v_tan = V₀ / η = 4.15 / 0.7 ≈ 5.93 m/s
Required wheel ω | ω = v_tan / r = 5.93 / 0.0325 ≈ 182.5 rad/s (1,743 rpm) ✓ matches actuator sizing

### 9.5 Subsystem Current Consumption

All logic subsystems are supplied at 5 V via buck converters from the 12 V rail. High-power actuators (stepper, DC motors) run directly at 12 V.

Subsystem | Component | V (V) | I typical (mA) | I max (mA)
Control | 2× ESP32 | 3.3 / 5 | 240 | 500
Lifting | NEMA 17 | 12 | 800 | 1,700
Lifting driver | A4988 | 5 (logic) | 10 | 50
Shooting | 2× FA-130 DC Motors | 12 | 600 | 1,200
Shooting driver | L298N | 12 | 36 | 100
Sorting | 2× SG90 Servo | 5 | 400 | 1,000
Sensing | TCS3200 | 5 | 3 | 5
Display | 2× 16×4 I2C LCD | 5 | 40 | 80

Ain Shams University | Faculty of Engineering | 2025–2026 | 32 / 45
Misc (buttons, LEDs) | – | 5 | 30 | 50
TOTAL at 12 V rail | | 12 | ~2.7 A | ~4.7 A

The PTC fuse on the custom PCB is rated at 5 A, providing ~6% headroom above peak load while protecting against short circuits. The 5 A power supply rating is confirmed adequate.

### 9.6 Power Source Sizing

For battery-powered operation (e.g., exhibitions), a 12 V LiPo battery is sized as follows:

Parameter | Value / Calculation
Avg. operating current | I_avg ≈ 2.5 A (actuators not all on simultaneously; 60% duty cycle assumed)
Desired runtime | 3 hours continuous
Required capacity | Q = I_avg × t = 2.5 × 3 = 7.5 Ah
Derate for depth of discharge | Q_rated = 7.5 / 0.8 ≈ 9.4 Ah → round up to 10 Ah
Recommended battery | 12 V, 10 Ah Li-ion / LiFePO4 pack or equivalent adapter
Buck converter efficiency | η ≈ 85%. I_12V for 5 V logic loads: I = (P_5V) / (12 × 0.85) ≈ 1.2 A additional

Ain Shams University | Faculty of Engineering | 2025–2026 33 / 45

## 10. Safety Considerations

The toy has been designed to comply with general children's toy safety principles applicable to the target age group of 2–10 years:

### 10.1 Mechanical Safety

- All 3D-printed parts are sanded and deburred post-printing to remove sharp edges and layer lines.
- The Archimedes screw is enclosed in a smooth cylinder — fingers cannot reach the spinning helix.
- Shooting wheel gap is sized for the specific marble diameter. No gap wide enough to trap fingers.
- Marble diameter > 35 mm — above the choking hazard threshold (ISO 8124-1 small parts cylinder test) for children aged 3+. An age label is applied for children under 3.
- All servo horn connections use recessed M2 screws to prevent protrusion injuries.
- No spring-loaded components under high tension accessible to the child.

### 10.2 Electrical Safety

- All wiring is routed through internal channels in the 3D-printed structure — no exposed conductors reachable by the child.
- JST connectors are keyed and polarised — incorrect reassembly is mechanically prevented.
- The custom PCB includes: reverse-polarity protection (1N5822 diode), over-current protection (5 A PTC resettable fuse), and decoupling capacitors to prevent voltage spikes.
- The 12 V supply uses a CE/UL-certified adapter with insulated barrel connector. No mains voltage enters the toy enclosure.
- All PCB traces are covered with solder mask; PCB is mounted in an enclosed housing within the base.
- The rocker switch is positioned on the rear of the toy, inaccessible during normal forward-facing play.

### 10.3 Thermal Safety

- Motor drivers (L298N, A4988) are fitted with heatsinks. No surface exceeds 50°C under normal operation.
- All plastic parts are PLA — safe and non-toxic. No ABS or other fume-emitting materials used.
- The PTC fuse provides thermal protection in case of sustained overload, resetting automatically once cooled.

### 10.4 Software Safety

- A hardware Start/Stop button is always active and takes immediate priority over Bluetooth commands.
- Watchdog timer is enabled on both ESP32 boards — if firmware hangs, the board resets within 8 seconds.
- Stepper and DC motors ramp up gradually (no instantaneous full-power starts) to reduce mechanical shock.

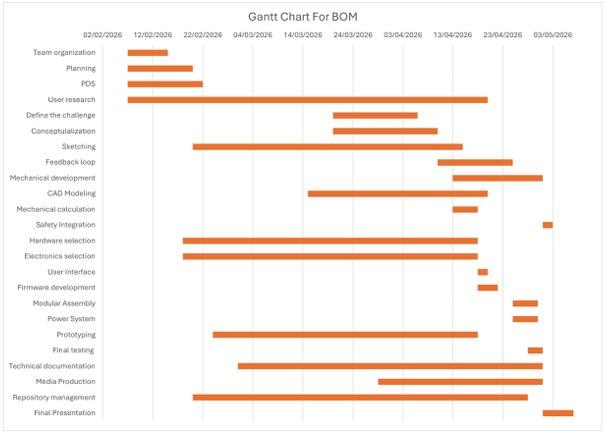
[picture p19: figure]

Ain Shams University | Faculty of Engineering | 2025–2026 34 / 45

## 11. Gantt Chart

The Gantt chart below outlines the full project timeline from team organisation (February 2026) through to the final presentation (May 2026). Tasks span six phases: project management, design thinking, mechanical development, electronics and firmware, fabrication, and documentation.

Figure 1 — Gantt Chart for BOM (February–May 2026)

Ain Shams University | Faculty of Engineering | 2025–2026 35 / 45

## 12. Work Breakdown Structure (WBS)

Phase 1 — Project Management & Preliminary Design

- 1.1 Team Organisation: Assign Mechanical Lead, Electronics Lead, Firmware Lead roles.
- 1.2 Planning: Create Gantt Chart to manage the project timeline.
- 1.3 Product Design Specification (PDS): Define technical and functional requirements.
- 1.4 User Research: Conduct research for the 2–10 age group.

Phase 2 — Design Thinking & Ideation

- 2.1 Define the Challenge: Formulate design challenge from user research findings.
- 2.2 Conceptualisation: Generate ideas via mind maps and mood boards.
- 2.3 Sketching: Create initial hand-drawn sketches of the toy concept.
- 2.4 Feedback Loop: Conduct iterative design cycles based on lab feedback.

Phase 3 — Mechanical Design & Analysis

- 3.1.1 Projectile-Based Shooting Mechanism: Design the dual-wheel launcher.
- 3.1.2 Vertical Lifting Mechanism: Design Archimedes screw and NEMA 17 drive.
- 3.1.3 Sorting Mechanism: Design colour-sensor gate system.
- 3.2 CAD Modelling: Create 3D models and assembly in Autodesk Inventor.
- 3.3 Mechanical Calculations: Actuator sizing, projectile motion.
- 3.4 Safety Integration: Ensure all moving parts are safe; verify 100 cm × 100 cm limit.

Phase 4 — Mechatronics & Control Systems

- 4.1 Hardware Selection: Purchase all required hardware.
- 4.2.1 Schematic Design: Circuit diagrams in Proteus / Cirkit Designer.
- 4.2.2 Custom PCB: Design and manufacture power distribution board.
- 4.2.3 Sensor Integration: Integrate TCS3200 for sorting.
- 4.3.1 Primary Interface: Program LCD displays.
- 4.3.2 Secondary Interface: Develop Bluetooth Processing IO application.
- 4.4 Firmware: Write Arduino/ESP32 code for closed-loop system with ESP-NOW.

Phase 5 — Fabrication & Integration

- 5.1 Modular Assembly: Build toy in modules with dedicated wiring plugs.
- 5.2 Power System: Integrate single 12 V source; verify current budget.
- 5.3 Prototyping: Build physical model using 3D printing and safe materials.
- 5.4 Final Testing: Full system test verifying closed-loop marble pathway.

Phase 6 — Deliverables & Documentation

- 6.1 Technical Documentation: Finalise Technical Report and Bill of Materials.
- 6.2 Media Production: Record project video with voiceover; design A0 poster.
- 6.3 Repository Management: Organise Git repository with correct folder structure.
- 6.4 Final Presentation: Prepare and deliver group presentation.

Ain Shams University | Faculty of Engineering | 2025–2026 36 / 45

## 12. Git Repository

All project files are maintained in a clean Git repository at: https://github.com/abdo-A028/MCT231-BASICS-OF-MECHATRONICS Repository structure follows the required convention:

Folder | Contents
/mechanical | Autodesk Inventor part files (.ipt), assembly files (.iam), exported drawings (.pdf/.dwg), STL files for 3D printing.
/electrical | Cirkit Designer / Proteus schematics, PCB source files (.kicad_pcb or equivalent), Gerber exports, component libraries.
/firmware_mcu1 | ESP32 Arduino sketch for Sorting & Lifting controller (MCU1). Includes ESP-NOW transmitter, TCS3200 driver, servo control, LCD library usage.
/firmware_mcu2 | ESP32 Arduino sketch for Shooting & Display controller (MCU2). Includes ESP-NOW receiver, A4988 stepper driver, L298N DC motor control.
/app | Processing IO application source code for the Bluetooth remote interface. Includes connection manager, button UI, and serial communication handler.
/docs | Technical report (this document), A0 poster PDF, PDS, test results, Gantt chart, user guide (Kids Guide).

## 13. A0 Poster

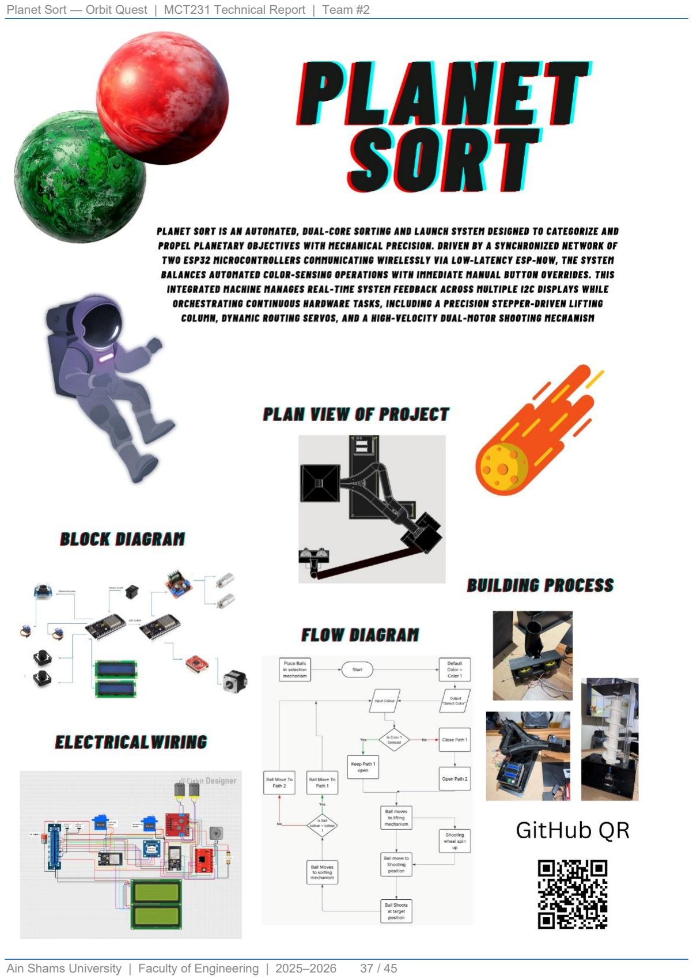
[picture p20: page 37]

Ain Shams University | Faculty of Engineering | 2025–2026 37 / 45

## 14. Rules for the toy

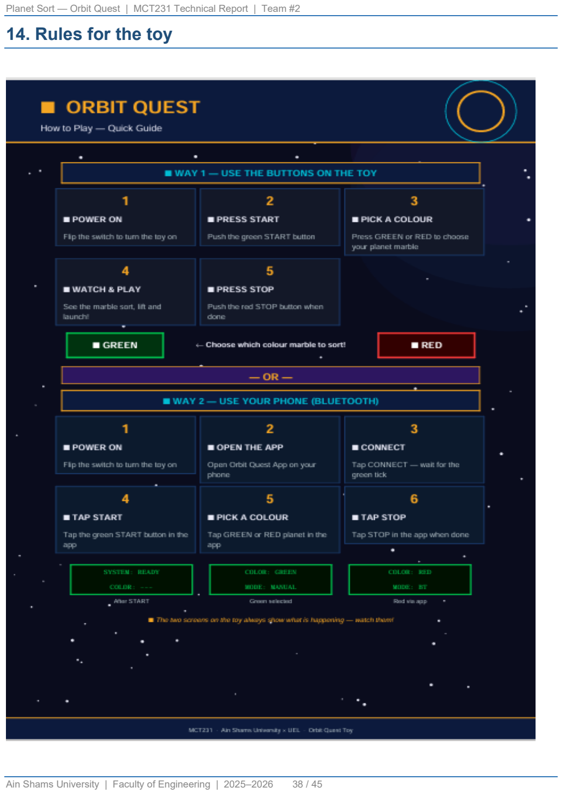
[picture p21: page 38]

Ain Shams University | Faculty of Engineering | 2025–2026 38 / 45

Ain Shams University | Faculty of Engineering | 2025–2026 39 / 45

## 15. Conclusion

The Planet Sort / Orbit Quest project successfully demonstrates a fully integrated mechatronic system designed as a children's toy. The team implemented three distinct mechanisms — colour-based sorting, Archimedes screw vertical lifting, and a dual-wheel projectile shooter — as a continuous, closed-loop marble pathway.
Key engineering achievements include:
- A dual-ESP32 architecture with wireless ESP-NOW communication providing low-latency, router-independent coordination between the sorting/lifting and shooting subsystems.
- Rigorous actuator sizing calculations (safety factors >2.2 for all motors) ensuring reliable performance without oversizing.
- A custom power distribution PCB with reverse-polarity protection, PTC fuse, and modular JST connectors enabling safe and maintainable wiring.
- A complete power budget confirming the 5 A, 12 V supply is adequate with headroom for peak loads, and a 10 Ah battery recommendation for portable operation.
- Full compliance with toy safety principles: no accessible moving parts, no exposed wiring, non-toxic materials, and marble sizing above the choking hazard threshold.
The design process followed the full design thinking methodology from user research and ideation through to physical prototype, documentation, and iterative refinement. All deliverables specified in the MCT231 course requirements have been addressed in this report and the accompanying repository.

The link of the video:
https://drive.google.com/file/d/1nRRADGn482Wg3E0Uluc1cbHO5MsvG_7m/view?usp=sharing Link for GitHub:
https://github.com/abdo-A028/MCT231-BASICS-OF-MECHATRONICS

## Appendix: Presentation Slides

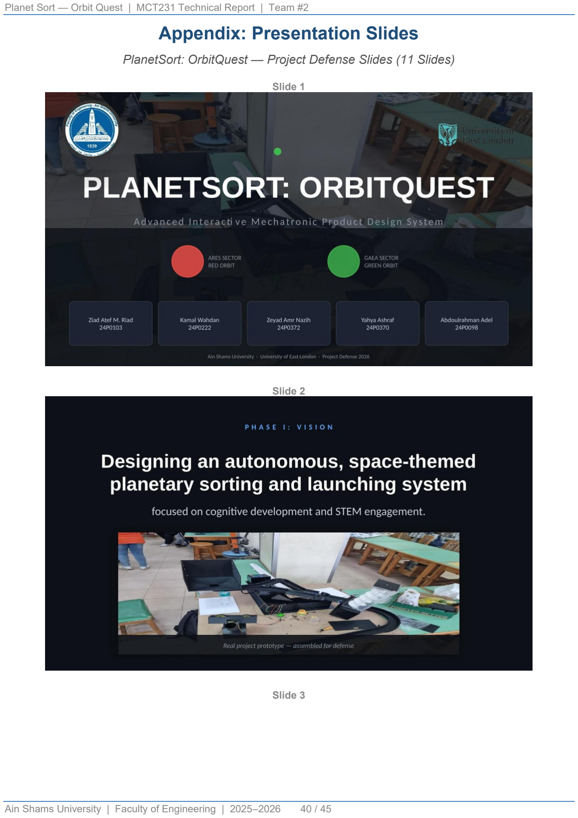
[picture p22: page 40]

Ain Shams University | Faculty of Engineering | 2025–2026 40 / 45

PlanetSort: OrbitQuest — Project Defense Slides (11 Slides)

Slide 1

Slide 2

Slide 3

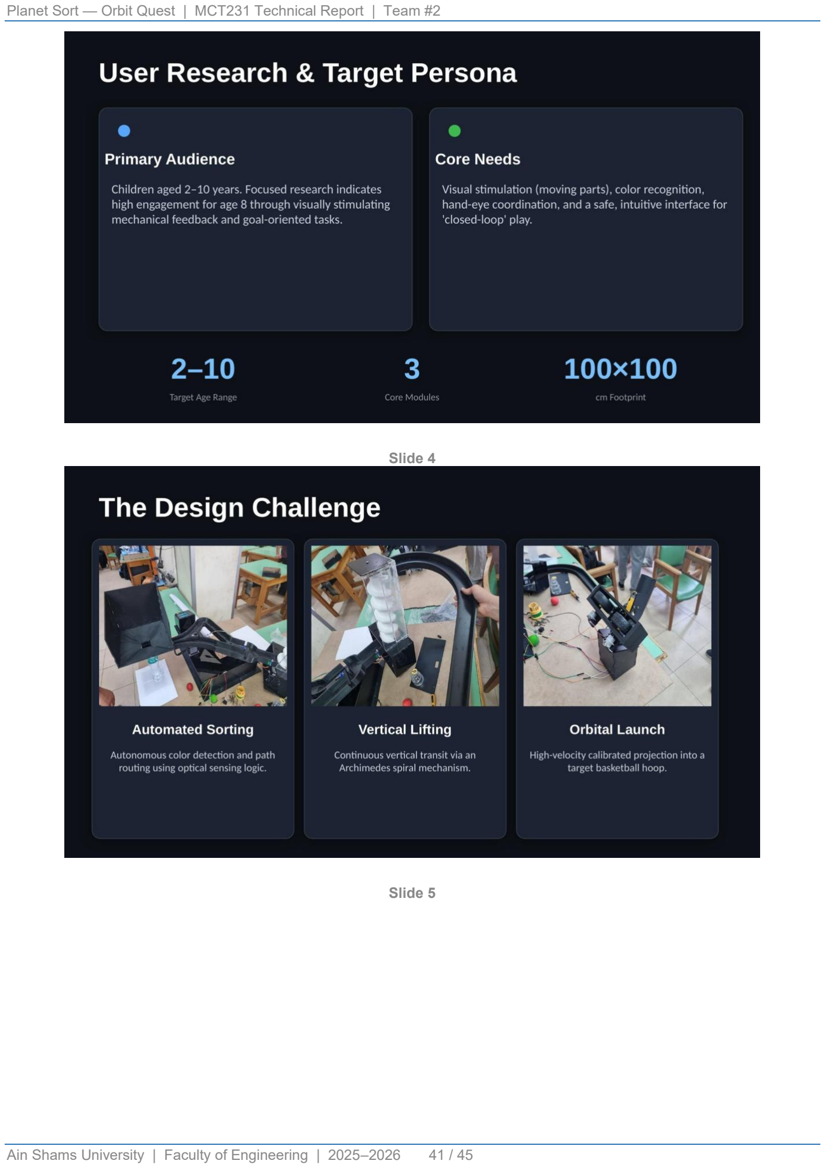
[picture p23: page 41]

Ain Shams University | Faculty of Engineering | 2025–2026 41 / 45

Slide 4

Slide 5

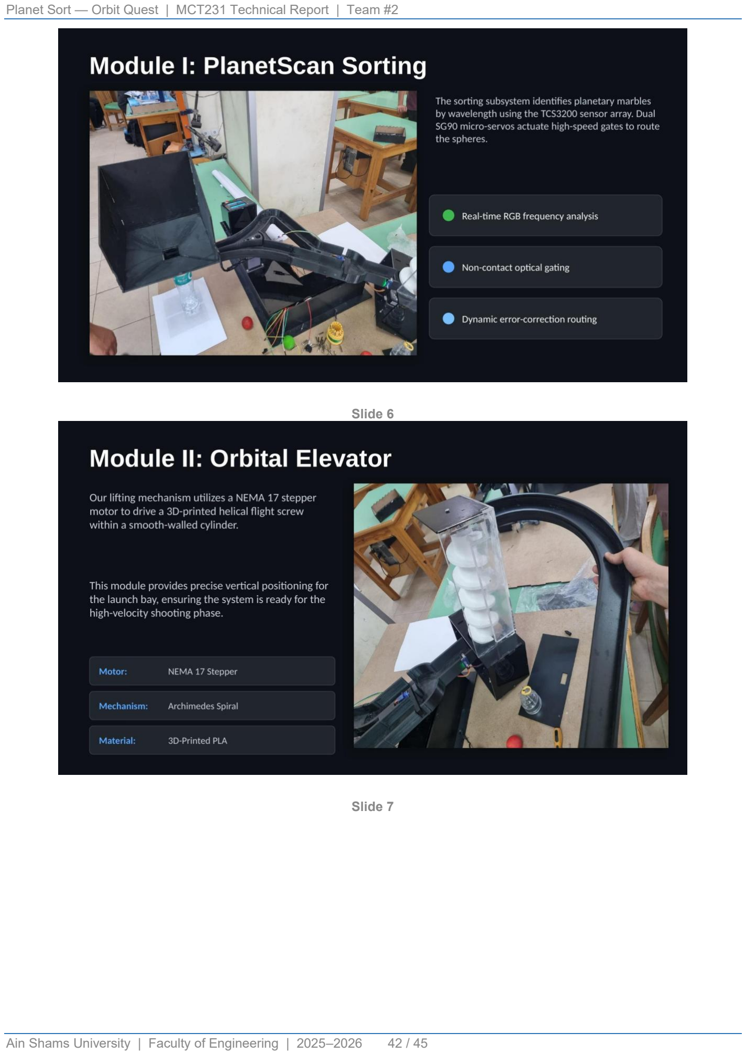
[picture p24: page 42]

Ain Shams University | Faculty of Engineering | 2025–2026 42 / 45

Slide 6

Slide 7

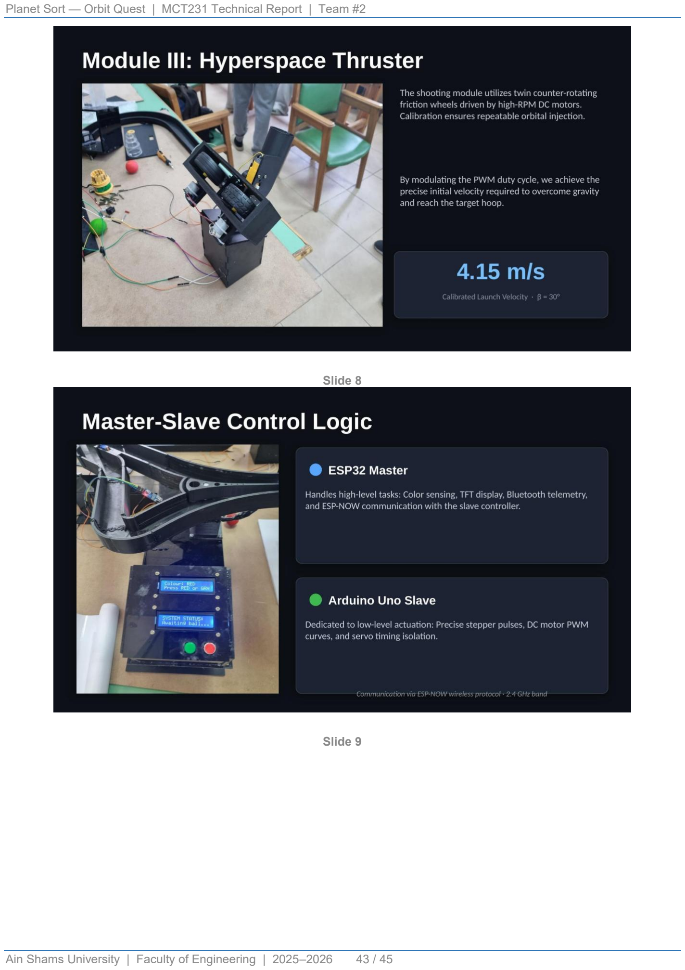
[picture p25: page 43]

Ain Shams University | Faculty of Engineering | 2025–2026 43 / 45

Slide 8

Slide 9


Ain Shams University | Faculty of Engineering | 2025–2026 44 / 45

Slide 10

Slide 11


Ain Shams University | Faculty of Engineering | 2025–2026 45 / 45

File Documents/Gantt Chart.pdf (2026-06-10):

Team organization; Planning; PDS; User research; Define the challenge; Conceptulalization; Sketching; Feedback loop; Mechanical development; CAD Modeling; Mechanical calculation; Safety Integration; Hardware selection; Electronics selection; User Interface; Firmware development; Modular Assembly; Power System; Prototyping; Final testing; Technical documentation; Media Production; Repository management; Final Presentation; Gantt Chart For BOM

02/02/2026 12/02/2026 22/02/2026 04/03/2026 14/03/2026 24/03/2026 03/04/2026 13/04/2026 23/04/2026 03/05/2026

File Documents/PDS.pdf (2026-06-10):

## Product Design Specification (PDS)

### 1. Performance & Functional Requirements

- Primary Function: An interactive basketball-themed toy where a ball is lifted, sorted, and shot into a hoop.
- Sorting Mechanism: A sensor-based system designed to differentiate balls specifically by color.
- Lifting Mechanism: A continuously rotating spiral screw (Archimedes' screw) to transport balls vertically.
- Shooting Mechanism: A projectile system calibrated to launch the ball into a basketball hoop.
- Closed-Loop System: A single-entry point for marbles/balls that must remain within the internal track throughout the cycle.
- Interactive Features: Must include at least one embedded interactive feature (e.g., buttons or sensors) and a dedicated Start/Stop button.

### 2. Electronics & Control System

- Microcontrollers: Two microcontrollers (e.g., Arduino Uno) using a standard communication protocol.
- User Interface 1: An onboard LCD/TFT Touch Display for direct interaction (No 7-segments).
- User Interface 2: A remote application built in Processing IO communicating via Bluetooth.
- Custom Electronics: At least one custom-manufactured PCB must be integrated into the system.
- Power: Powered by a single unified power source.

### 3. Physical & Material Specifications

- Manufacturing: Primary structural and mechanical components will be 3D printed.
- Dimensions: Total assembly must not exceed 100 cm x 100 cm.
- Modularity: The design must be divided into modules with individual wiring plugs for easy assembly and disassembly.
- Safety: All wiring must be hidden; the 3D-printed surfaces must be smooth and safe for the target age group.

### 4. Target Audience

- User Profile: Designed for children aged 8 years old ($\pm$ 6), focusing on engagement levels suitable for older children while maintaining safety for younger ones.

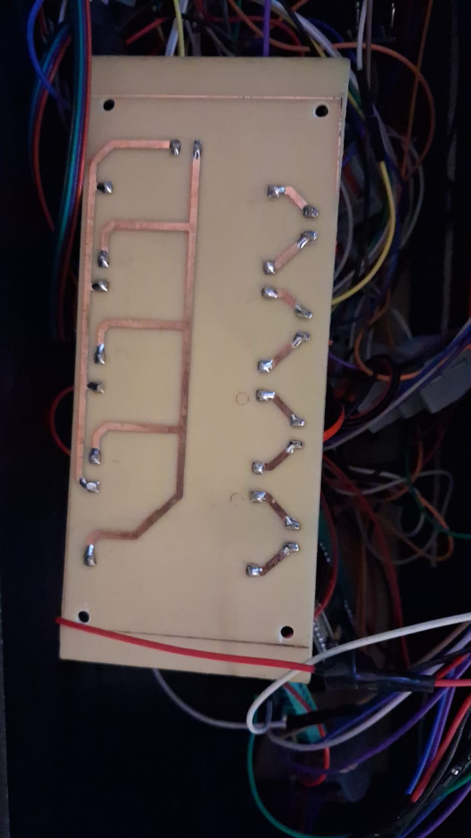
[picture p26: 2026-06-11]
Electrical/Schematics/WhatsApp Image 2026-06-11 at 11.09.48 PM.jpeg

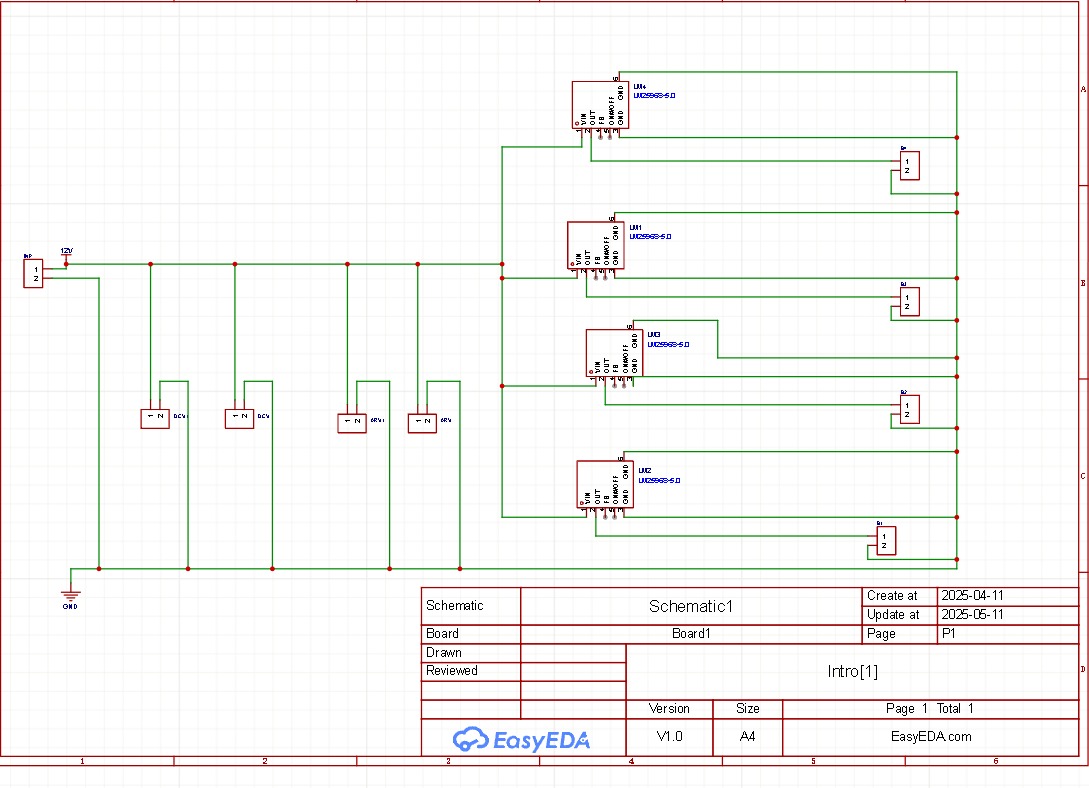
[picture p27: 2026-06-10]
Electrical/Schematics/WhatsApp Image 2026-06-10 at 8.53.47 PM.jpeg

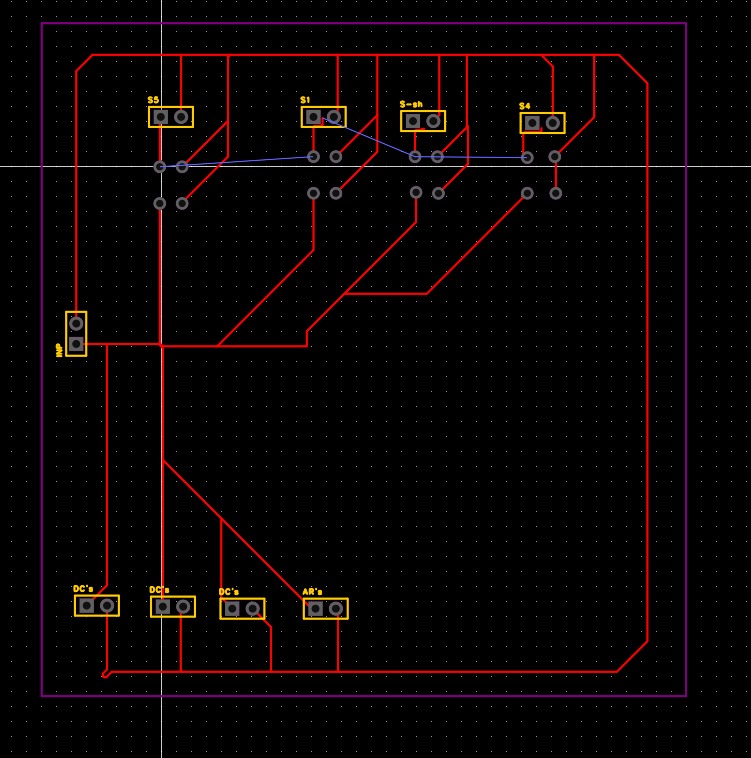
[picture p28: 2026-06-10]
Electrical/Schematics/WhatsApp Image 2026-06-10 at 8.53.46 PM.jpeg

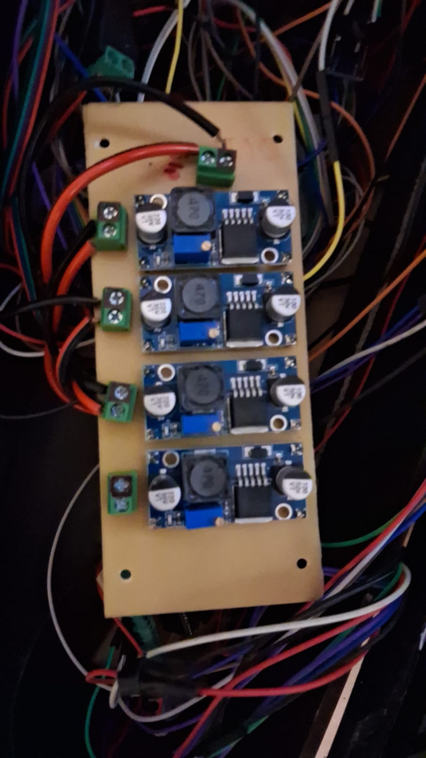
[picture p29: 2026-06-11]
Electrical/Schematics/WhatsApp Image 2026-06-11 at 11.09.38 PM.jpeg

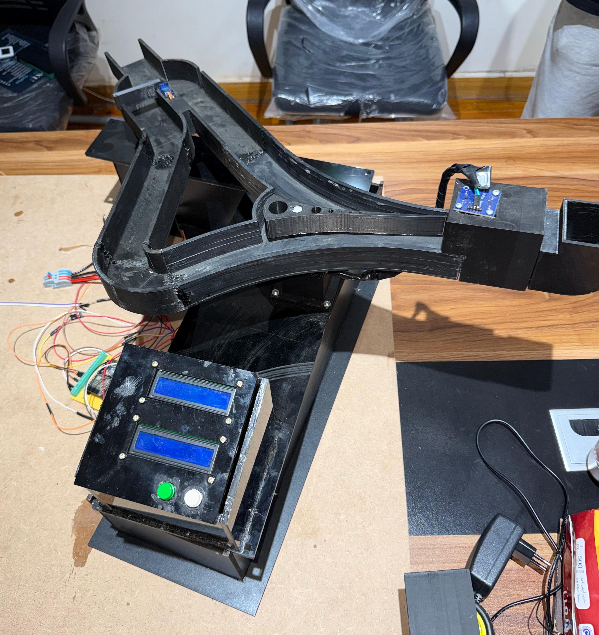
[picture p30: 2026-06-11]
Mechanical/Screenshot/WhatsApp Image 2026-06-10 at 10.48.29 PM.jpeg

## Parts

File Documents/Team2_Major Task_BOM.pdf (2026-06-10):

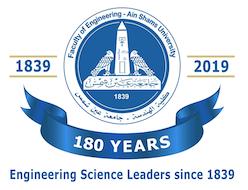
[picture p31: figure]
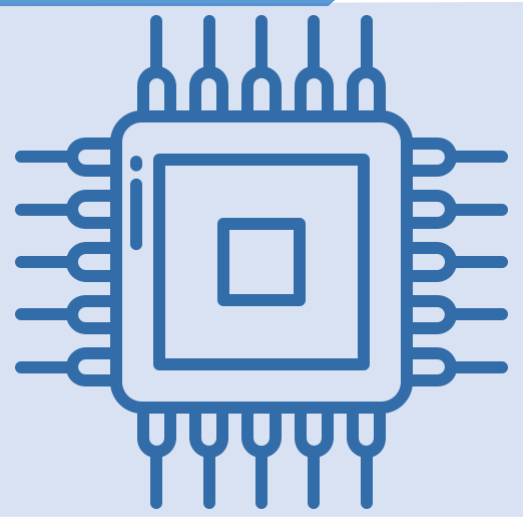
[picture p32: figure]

Ziad Atef Mohamed Riad | 24P0103
Kamal Wahdan | 24P0222
Zeyad Amr Nazih | 24P0372
Yahya Ashraf | 24P0370
Abdoulrahman Adel | 24P0098

# AIN SHAMS UNIVERSITY

# Major Task

# Team #2

## Basics of Mechatronics – MCT231

1

# TABLE OF CONTENTS

# 1 Work Breakdown Structure (WBS)

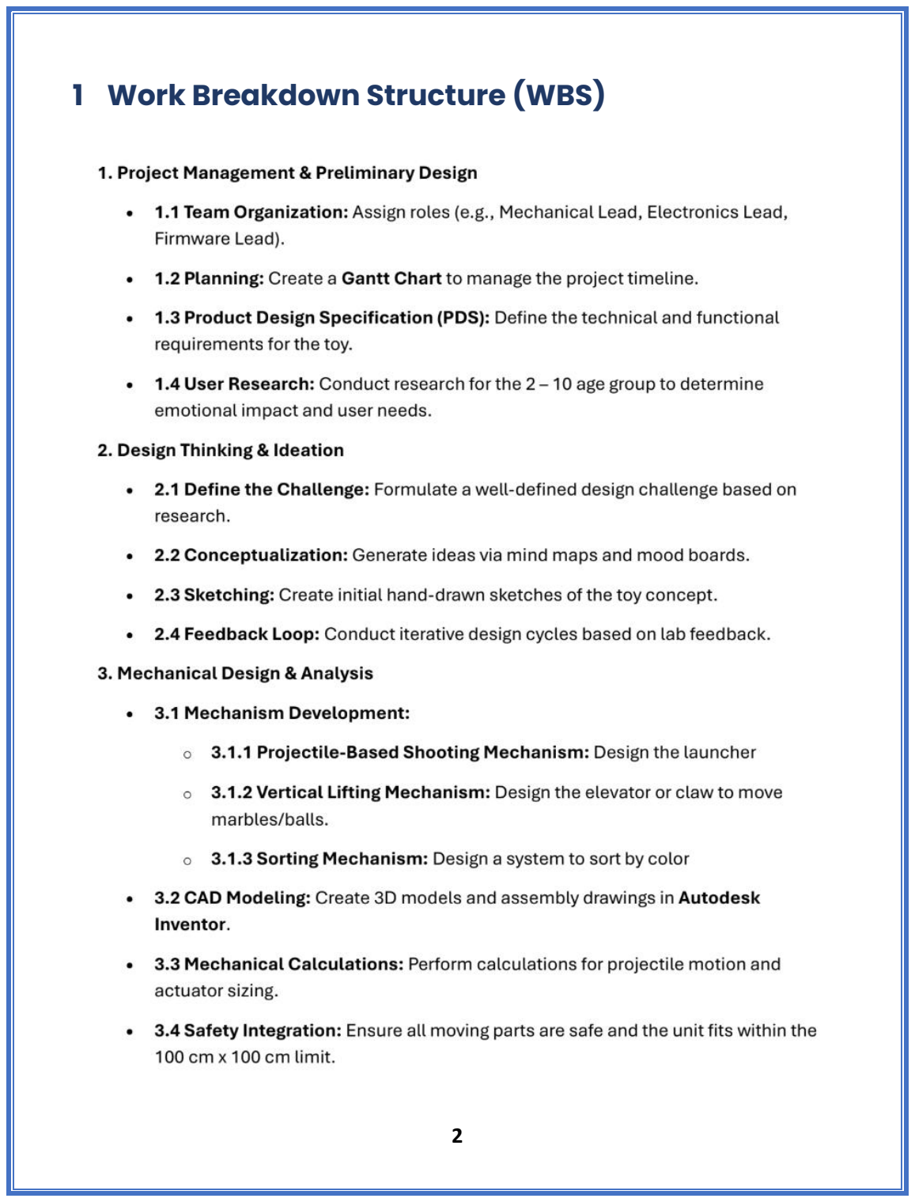
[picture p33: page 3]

2

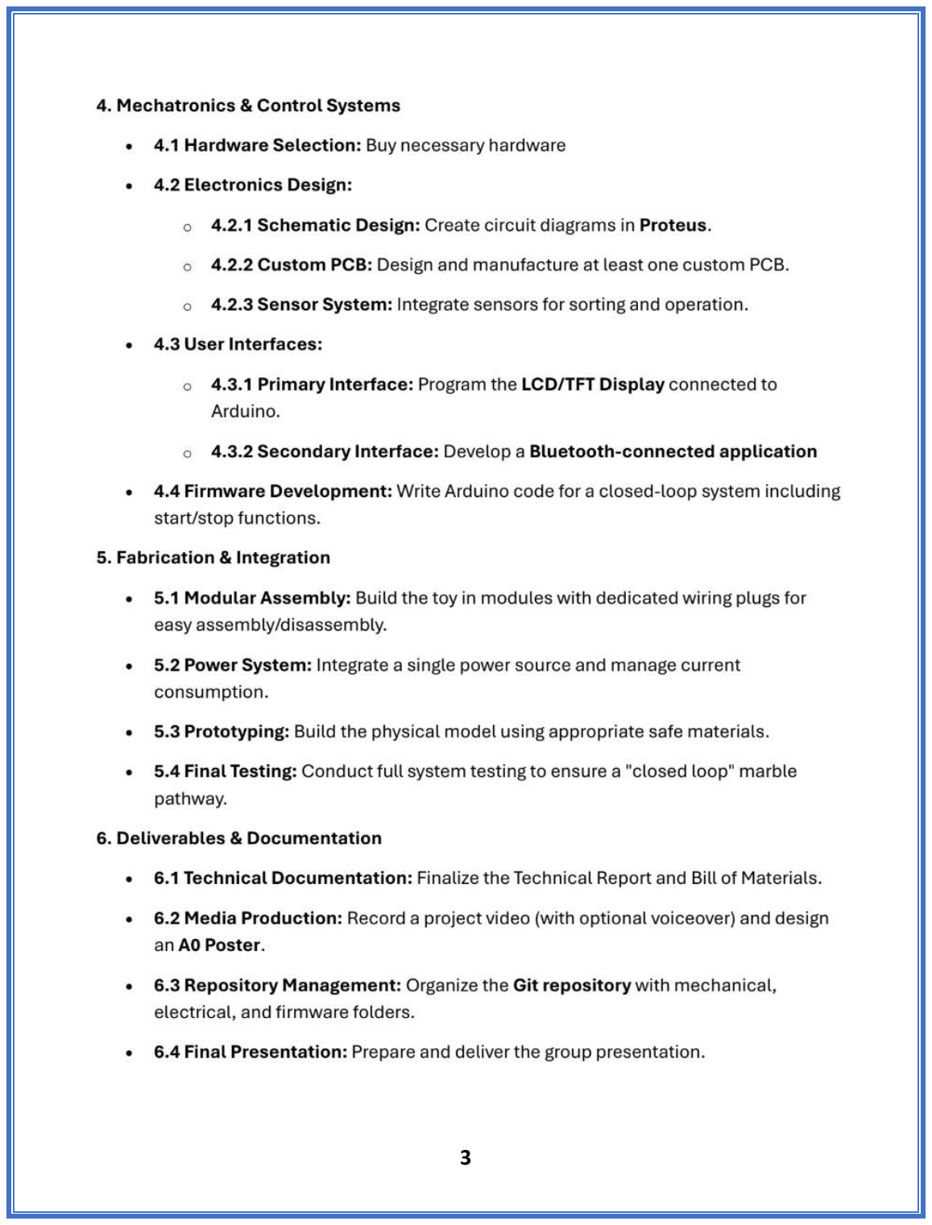
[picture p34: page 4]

3

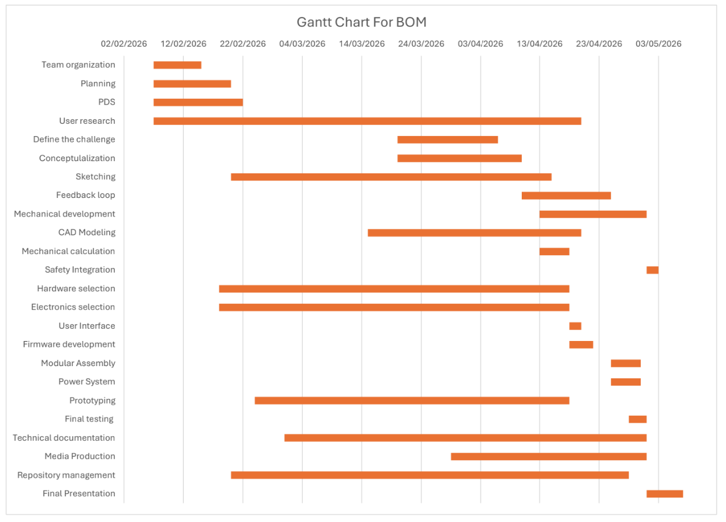
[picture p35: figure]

4

# 2 Gantt Chart

5

# 3 Product Design Specification (PDS)

### 1. Performance & Functional Requirements

- Primary Function: An interactive basketball-themed toy where a ball is lifted, sorted, and shot into a hoop.
- Sorting Mechanism: A sensor-based system designed to differentiate balls specifically by color.
- Lifting Mechanism: A continuously rotating spiral screw (Archimedes' screw) to transport balls vertically.
- Shooting Mechanism: A projectile system calibrated to launch the ball into a basketball hoop.
- Closed-Loop System: A single-entry point for marbles/balls that must remain within the internal track throughout the cycle.
- Interactive Features: Must include at least one embedded interactive feature (e.g., buttons or sensors) and a dedicated Start/Stop button.

### 2. Electronics & Control System

- Microcontrollers: Two microcontrollers (e.g., Arduino Uno) using a standard communication protocol.
- User Interface 1: An onboard LCD/TFT Touch Display for direct interaction (No 7-segments).
- User Interface 2: A remote application built in Processing IO communicating via Bluetooth.
- Custom Electronics: At least one custom-manufactured PCB must be integrated into the system.
- Power: Powered by a single unified power source.

### 3. Physical & Material Specifications

- Manufacturing: Primary structural and mechanical components will be 3D printed.
- Dimensions: Total assembly must not exceed 100 cm x 100 cm.
- Modularity: The design must be divided into modules with individual wiring plugs for easy assembly and disassembly.
- Safety: All wiring must be hidden; the 3D-printed surfaces must be smooth and safe for the target age group.

### 4. Target Audience

User Profile: Designed for children aged 8 years old ($\pm$ 6), focusing on engagement levels suitable for older children while maintaining safety for younger ones.

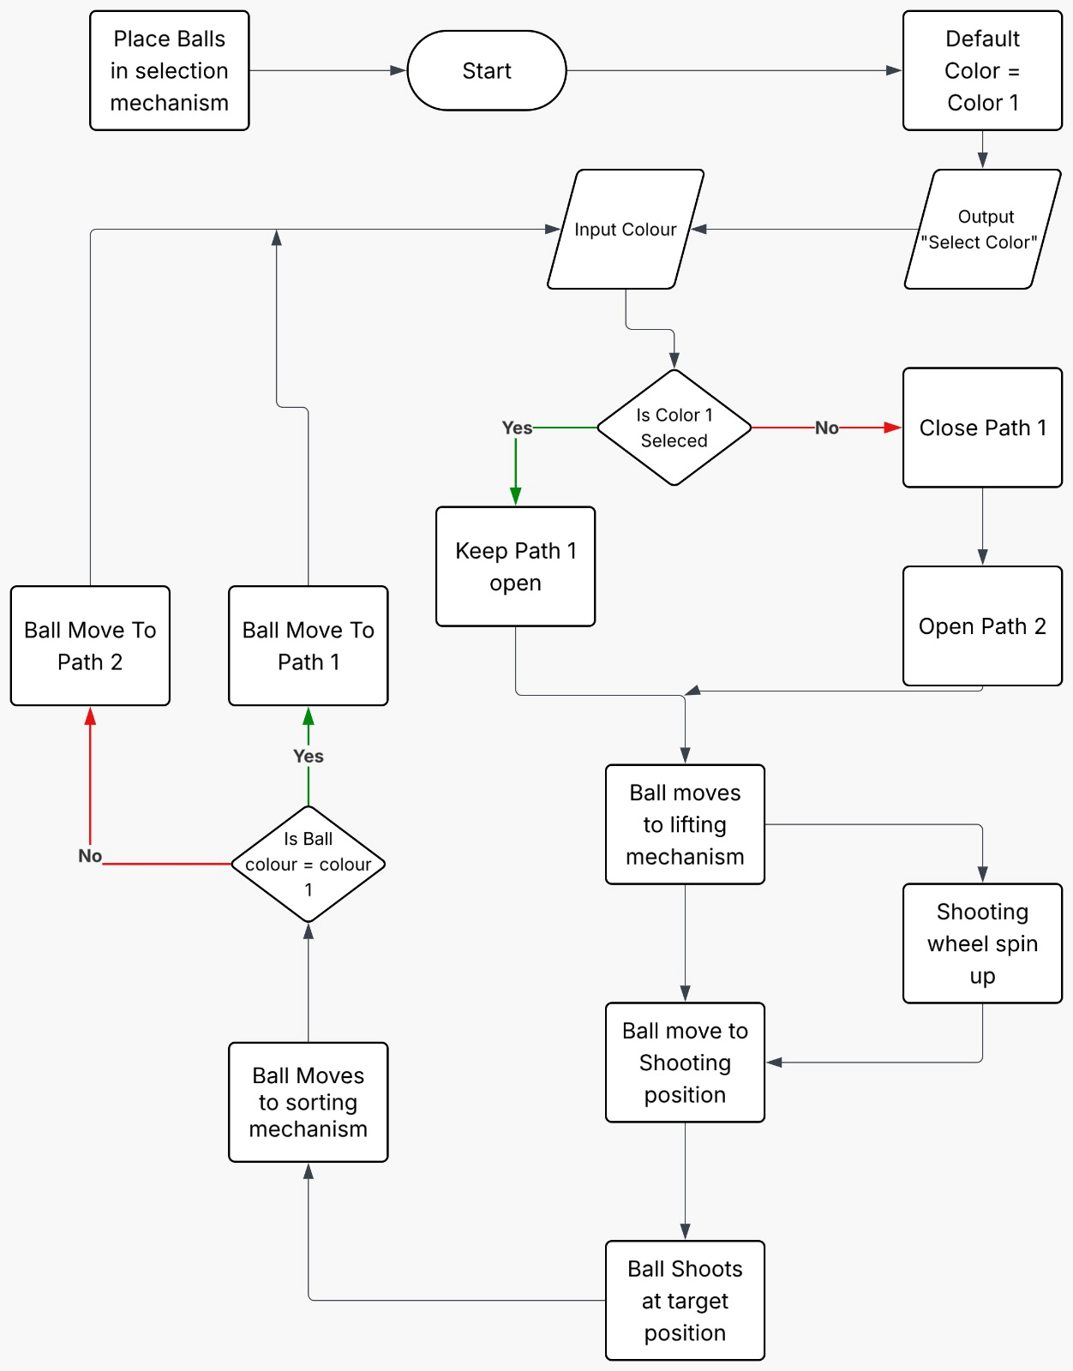
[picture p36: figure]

6

# 4 System Flowchart

# 5 Block Diagram

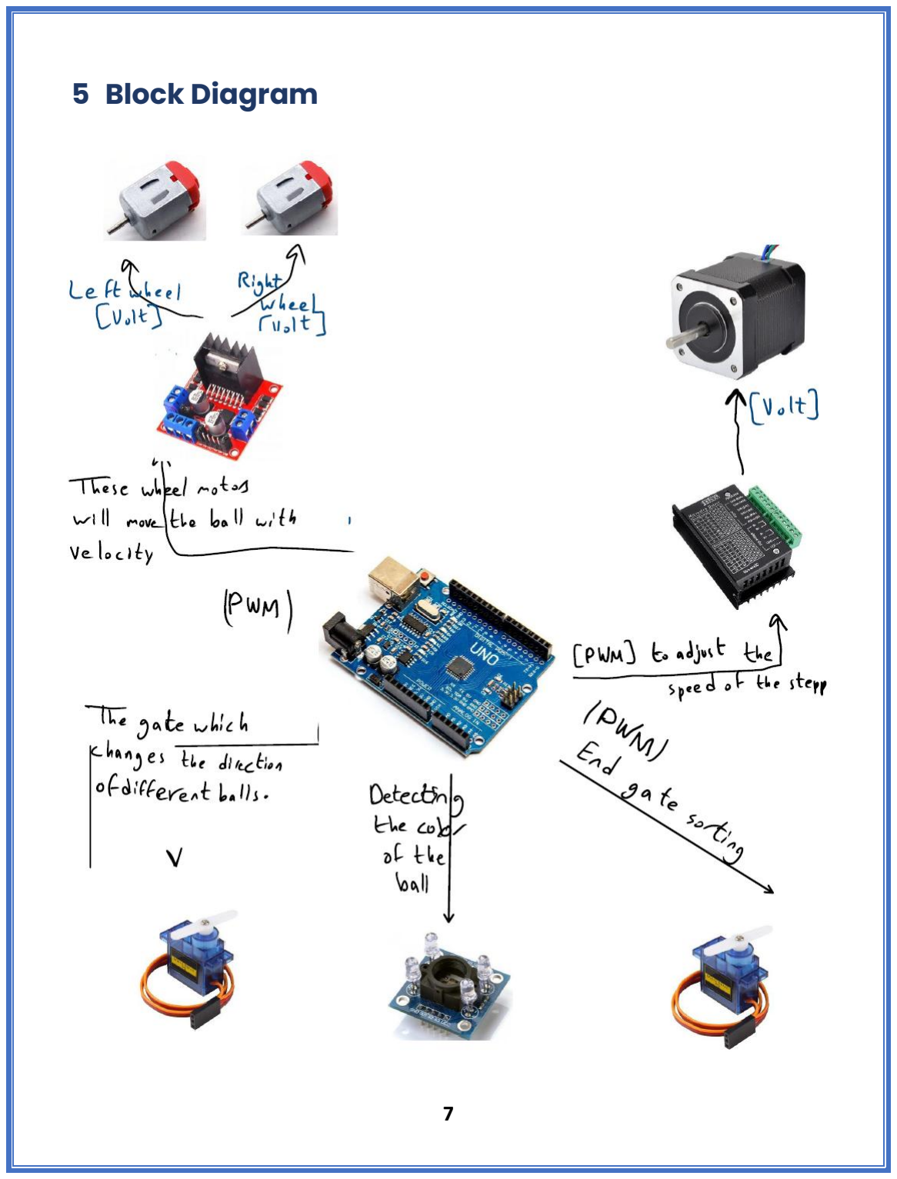
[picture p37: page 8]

7

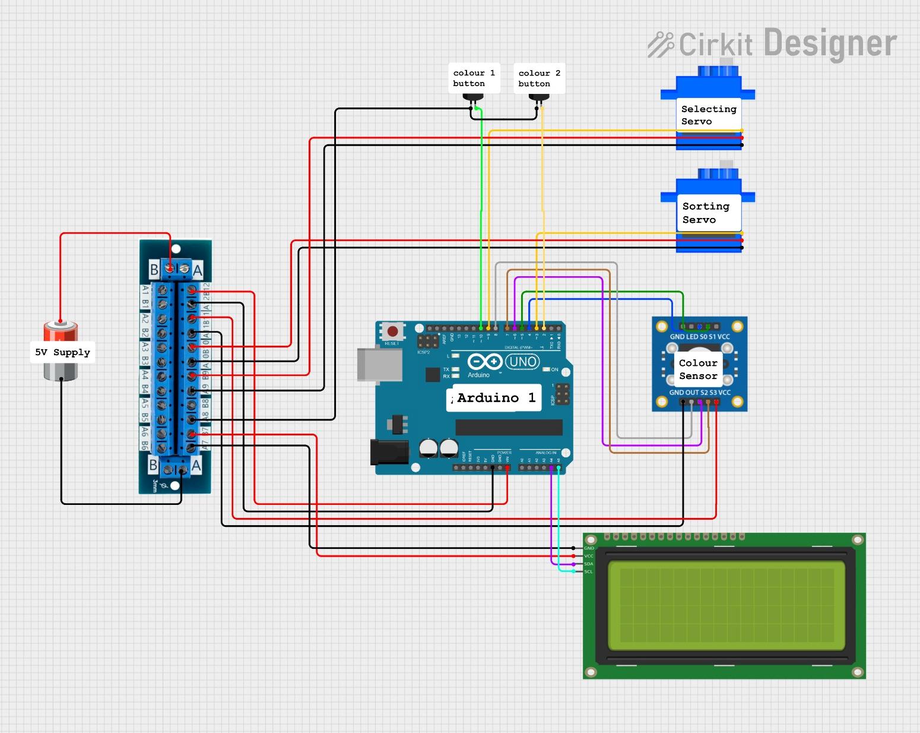
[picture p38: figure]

8

# 6 Wiring Diagrams

## 6.1 Sorting:

## 6.2 Lifting:


9

## 6.3 Shooting:

# 7 PCB Schematic


10


11

# 8 Fully integrated CAD Design


12

# 9 Actuator Sizing

## 9.1 Sorting:


13

## 9.2 Lifting:

## 9.3 Shooting:


14


15

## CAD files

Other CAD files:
Mechanical/Assembly/Archimedes Screw V2.ipt
Mechanical/Assembly/Assembly1.iam
Mechanical/Assembly/Base Connection.ipt
Mechanical/Assembly/Base lif.ipt
Mechanical/Assembly/Base.ipt
Mechanical/Assembly/Base2.ipt
Mechanical/Assembly/Collector.ipt
Mechanical/Assembly/Container Tube v2.ipt
Mechanical/Assembly/Exit.ipt
Mechanical/Assembly/Full Project Assembly.iam
Mechanical/Assembly/Insert.ipt
Mechanical/Assembly/LCD.ipt
Mechanical/Assembly/Landing Holder.ipt
Mechanical/Assembly/Motor12v.iam
Mechanical/Assembly/Part3.ipt
Mechanical/Assembly/SG90_Arm_Original.ipt
Mechanical/Assembly/SG90_Model_A.ipt
Mechanical/Assembly/SG90_Model_X.ipt
Mechanical/Assembly/SHOOT CAD FINAL.iam
Mechanical/Assembly/Select Holding Pins.ipt
Mechanical/Assembly/Selection Body V1.ipt
Mechanical/Assembly/Servo_Shaft_V2.ipt
Mechanical/Assembly/Servo_Shaft_select_V1.ipt
Mechanical/Assembly/Servo_Shaft_select_V2.ipt
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

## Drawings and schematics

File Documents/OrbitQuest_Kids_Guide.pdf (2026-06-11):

# ■ ORBIT QUEST

1

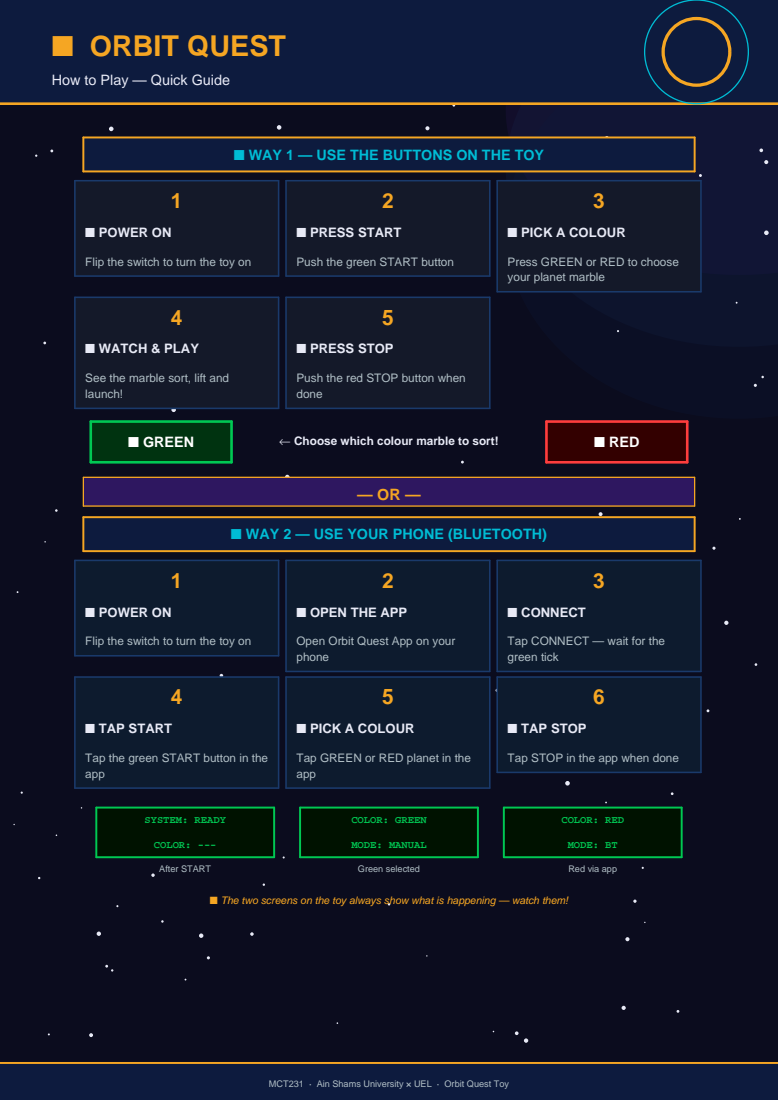
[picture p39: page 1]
■ POWER ON; ■ PRESS START; ■ PICK A COLOUR; ■ WATCH & PLAY; ■ PRESS STOP; ■ GREEN; ← Choose which colour marble to sort!; ■ RED; ■ CONNECT; ■ TAP START; ■ TAP STOP; SYSTEM: READY; COLOR: ---; After START; COLOR: GREEN; MODE: MANUAL; Green selected; COLOR: RED; MODE: BT

How to Play — Quick Guide

■ WAY 1 — USE THE BUTTONS ON THE TOY

Flip the switch to turn the toy on

Push the green START button

Press GREEN or RED to choose
your planet marble

See the marble sort, lift and
launch!

Push the red STOP button when
done

■ WAY 2 — USE YOUR PHONE (BLUETOOTH)

■ OPEN THE APP

Open Orbit Quest App on your
phone

Tap CONNECT — wait for the
green tick

Tap the green START button in the
app

Tap GREEN or RED planet in the

Tap STOP in the app when done

Red via app

■ The two screens on the toy always show what is happening — watch them!

MCT231 · Ain Shams University × UEL · Orbit Quest Toy

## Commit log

2026-06-10 Create Assembly
    This is for CAD design me and my team did, the photos and screenshot of the tool in real life is on another one
2026-06-10 Add CAD file to Mechanical Assembly directory + Add Screenshot folder to Mechanical directory
2026-06-10 Add placeholder for prototype photos
2026-06-10 Add link to electrical structure schematics
